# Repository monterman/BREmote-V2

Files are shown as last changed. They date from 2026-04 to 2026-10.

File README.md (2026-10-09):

# BREmote V2.5-Evo — Tow Buggy / eFoil Remote

> **Fork of [BREmote V2](https://github.com/Luddi96/BREmote) by LudwigBre / Luddi96**





ESP32 LoRa wireless remote for efoil and RC tow buggy — 868/915 MHz, 10 Hz control cycle, VESC UART telemetry, GPS speed display, integrated data logger.

**Status: Alpha — BLE + VESC Tool field-confirmed ✅ (2026-05-16). RTM encoded + working, FM coded.**

> **🌙 nightly firmware.** The sections marked *upcoming release*, the setup wizard and the new
> screens match the **nightly** firmware on the [`fm-stations` branch](https://github.com/monterman/BREmote-V2/tree/fm-stations), not the
> firmware on master. Nightly = bleeding edge, under water testing, use at your own risk.
> Binaries are in the `latest-FM-stations` folders. See [Nightly builds](#-nightly-builds).

> **⚠️ 2026-07-25 — important fix, please reflash both boards.** A bug was found in on-water testing: the shared serial line was prioritising the VESC over the GPS, so the receiver was catching only ~2% of the GPS feed and Follow-Me could steer on a dead heading. Priority is now swapped and the GPS course works. **Fixed but not yet proven on the water** — see [CHANGELOG.md](CHANGELOG.md). Read the Alpha Testing Notes below before any in-water use.**

> **🆕 Upcoming release — new Follow-Me screens, auto-return, front stations, buggy WiFi console.**
> In the nightly builds on the [`fm-stations` branch](https://github.com/monterman/BREmote-V2/tree/fm-stations) now; it moves to master
> gradually after more water testing. See [what's coming](#-coming-in-the-upcoming-release) and the
> [release notes](docs/RELEASE_NOTES_upcoming.md).

---

## 🚀 New here? Start with the setup guide

### **[→ Zero → Foiling — the complete setup walkthrough](docs/ZERO_TO_FOILING.md)**

**Out of the box to on the water, in one linear path.** Flashing, TX calibration, pairing, compass
calibration, VESC/PPM wiring and setup, the wheels-up safety check, web-portal configuration, the dry
arming test, and your first Follow-Me session. If you are setting up a BREmote for the first time,
**read that guide, not this page.**

### **[→ Setup wizard — get your settings in about 8 minutes](https://monterman.github.io/BREmote-V2/setup-wizard.html)**

Answer a few questions about your buggy, remote and riding, and the wizard gives you the settings for
both boards, ready to load with the web serial config tool (USB) or from your phone on the board's
WiFi page. *Matches the nightly firmware on the `fm-stations` branch.*

This README is the reference: what the hardware is, what changed in each version, what every setting
and status code means, and what is still broken. Come back to it once you are running.

📁 **[Browse all the detailed guides in `docs/` →](docs/)** — wiring, flashing, GPS, compass, VESC
tuning, display reference and more. The [index below](#-detailed-guides--where-to-go-deeper) says
which one you want.

---

## 📚 Detailed guides — where to go deeper

Every section of this README has a longer document behind it. Start here when you need the detail:

| If you want to… | Read |
|---|---|
| **Set up from scratch, in order** | **[Zero → Foiling](docs/ZERO_TO_FOILING.md)** ⭐ start here |
| **Flash the boards** | **[Flashing with the Flash Download Tool](docs/FLASHING_WITH_DOWNLOAD_TOOL.md)** ⭐ the normal way — no Arduino · 🎥 [video from 40:00](https://youtu.be/r6JIZEq3aTU?t=2400) |
| Compile it yourself *(advanced)* | [RX via Arduino](docs/FLASHING_RX_ARDUINO.md) · [TX via Arduino](docs/FLASHING_TX_ARDUINO.md) |
| Wire the GPS + compass to the RX | [BN-880 → RX wiring](docs/GPS_Wiring_BN880_RX.md) |
| **Mount the GPS/compass OUTSIDE the box** | **[External GPS + compass mount](docs/External_GPS_Compass_Mount.md)** ⭐ the single biggest fix for compass error — 10 in max, waterproofed, nothing ferrous |
| Understand or fix GPS | [GPS configuration](docs/GPS.md) · [GPS troubleshooting](docs/hardware/gps-troubleshooting.md) |
| Calibrate the compass | **[Zero → Foiling § 2.4](docs/ZERO_TO_FOILING.md#24-compass-calibration-rx--nose-on-north-two-clockwise-circles)** — the procedure: nose on north, two clockwise circles, finish on north |
| Chase compass EMI / understand the field data | [Compass calibration & EMI field analysis](docs/Compass_Cal_Analysis.md) *(reference, not a how-to)* |
| Read the TX screen | [Display reference](docs/display-reference.md) |
| Ride with Follow-Me | [Follow-Me guide](docs/FOLLOW_ME_GUIDE.md) · [design notes](DESIGN_FOLLOW_ME.md) |
| See the new Follow-Me screens *(upcoming release)* | **[Screens page + glance quiz](https://monterman.github.io/BREmote-V2/followme-screens.html)** |
| Get a starting config for your setup *(upcoming release)* | **[Setup wizard](https://monterman.github.io/BREmote-V2/setup-wizard.html)** |
| What the next firmware changes | [Upcoming release notes](docs/RELEASE_NOTES_upcoming.md) |
| Use Return-to-Me | [RTM design notes](DESIGN_RETURN_TO_ME.md) |
| Set up or tune the VESCs | [Smooth-start quick reference](docs/VESC_SMOOTH_START_QUICK_REFERENCE.md) · [tuning process](docs/VESC_TUNING_PROCESS.md) · [FOC notes](docs/VESC_FOC_TUNING_NOTES.md) |
| Fix VESC telemetry | [VESC telemetry fix](docs/VESC_Telemetry_Fix.md) · [telemetry sources & prop baseline](docs/TELEMETRY_SOURCE_AND_PROP_BASELINE.md) |
| Use Bluetooth / BLE | [BLE implementation](docs/BLE_Implementation.md) · [app brief](docs/BLE_App_Brief.md) |
| Pull and read logs | [Logger notes](docs/LOGGER_NOTES.md) |
| Fit the magnet / Hall sensor | [Install tutorial](docs/Hall_Sensor_Install_Tutorial.md) · [expansion notes](docs/Hall_Sensor_Expansion.md) |
| Tune heading control | [Heading control tuning](docs/Heading_Control_Tuning.md) |
| Understand the throttle path | [Throttle pipeline analysis](docs/THROTTLE_PIPELINE_ANALYSIS.md) |
| Help test, and report properly | [Beta testing sheet](docs/Beta_Testing_Sheet.md) |
| Understand the safety model | [Buggy foil domain](BUGGY_FOIL_DOMAIN.md) |

---

## Contributors

People who have tested, reported, or contributed code to **this fork** specifically. Upstream credit
for the original hardware and firmware is in [Credits](#credits) below.

| | |
|---|---|
| **[robertzach](https://github.com/robertzach)** *(heiguga)* | First outside contributor. Brought **HGLRC M100-5883** support — his [PR #1](https://github.com/monterman/BREmote-V2/pull/1) identified that the module carries a **QMC5883P at 0x2C**, not the QMC5883L the firmware assumed, and his working implementation read from register `0x01`. That independently confirmed the QST datasheet against ArduPilot's driver, which has that init write transposed — so his code was the tiebreaker on a real ambiguity. Also field-tested the dual-compass build within hours of release, and hit the Sea-model altitude ceiling at 550 m, which is why `gps_dyn_model` exists. |

---

## Credits

BREmote is a collaborative open-source project built by the efoil and esk8 community:

| Contributor | Contribution |
|---|---|
| **[LudwigBre / Luddi96](https://github.com/Luddi96/BREmote)** | **Original hardware design, original firmware architecture, project founder, and dev-logger framework (dev-logger branch). All core features originate here.** |
| **Janrusher** | Dynamic throttle cap mode and Web Console foundation — significant V2 enhancements forked from LudwigBre, further refined in V2.5-Evo |
| **monterman** | V2.5-Evo firmware: TX GPS implementation, dev-logger AUX button toggle with LED status feedback (5× flash = start, 2× flash = stop), date format DDMMYY → MMDDYY, web console major rebuild (upload/download/compare JSON, integrated serial console, TX+RX coverage, plain-English parameter docs for every setting), deep codebase analysis, critical bug documentation, RTM/FM mode design, VESC UART telemetry diagnosis and root-cause fix (SW55), DISPLAY_MODE_INTBAT 7th display mode, BT status dot + Hall sensor activation framework, BLE NUS + VESC Tool binary protocol live gauges (field-confirmed 2026-05-16) |

This fork exists because LudwigBre published open hardware and firmware under GPL 3.0. V2.5-Evo enhancements are released under the same license and dedicated back to the community.

### Branches — read this before you clone

| Branch | What it is |
|---|---|
| **`master`** | **V2.5-Evo. The default branch, and what you want.** Hardware-verified on both boards. |
| `ludwig-upstream-main` | **LudwigBre's original line, not mine.** Kept so upstream changes can be tracked and merged. Do not flash it expecting V2.5-Evo behaviour — it is a different firmware. |
| `fm-stations` | **Nightly builds** — bleeding edge, under water testing, use at your own risk: new Follow-Me screens, auto-return, front stations, buggy WiFi console. Binaries in the `latest-FM-stations` folders. Commits move to master gradually after more water testing. See [Nightly builds](#-nightly-builds). |
| `multi-tx` | Work in progress: multiple remotes sharing one buggy. **Nothing here has been flashed to hardware.** |

`ludwig-upstream-main` was called `main` until 2026-08-05. It was renamed because "main" reads
like the primary branch of *this* repo, which it is not — it is a mirror of
[Luddi96/BREmote](https://github.com/Luddi96/BREmote), whose own default branch is `main`. The
old name caused exactly the confusion the new one avoids.

---

## What Is This?

BREmote is a custom wireless remote system for efoils and RC tow buggies. The TX (handheld) sends throttle and steering over LoRa at 10 Hz. The RX (mounted on the vehicle) drives the ESC/VESC and returns telemetry.

```
┌────────────────────────────┐              ┌──────────────────────────────────┐
│      TX — Handheld         │              │       RX — Board Unit            │
│                            │              │                                  │
│  ESP32-C3                  │              │  ESP32-C3                        │
│  SX1262 LoRa               │◄──────────►  │  SX1262 LoRa                     │
│  BN-220 GPS (GPIO 18/19)   │  868/915MHz  │  BN-880 GPS  (Serial1 + I2C mux) │
│  Dot matrix display        │    10 Hz     │  Compass QMC5883L or 5883P (I2C) │
│  Hall-effect throttle      │  6-byte pkt  │  AW9523 I/O Expander (I2C)       │
│  Hall-effect toggle        │              │  VESC UART  or  ESC PWM output   │
│  Vibration motor           │              │  Servo steering output           │
│  WiFi AP — web config      │              │  WiFi AP — web config + log DL   │
│                            │              │  Flash Data Logger               │
└────────────────────────────┘              └──────────────────────────────────┘
```

---

## 🆕 Coming in the upcoming release

*In the nightly builds on the [`fm-stations` branch](https://github.com/monterman/BREmote-V2/tree/fm-stations) now (see
[Nightly builds](#-nightly-builds)). It moves to master gradually after more water testing. Flash the
remote and the buggy together.* Details: [release notes](docs/RELEASE_NOTES_upcoming.md).

- **New Follow-Me screens.** One dot hopping = waiting, two steady dots = following, the dot column
  filling down = the buggy is coming to you. The numbers are the metres between remote and buggy.
  [See them animated, with a glance quiz](https://monterman.github.io/BREmote-V2/followme-screens.html).
- **Auto-return inside Follow-Me.** Stop and the buggy parks and waits. Squeeze when you want it
  back. Pauses never cancel it; it ends by arriving, a fault, or switching the remote off and on.
- **Magnet tap** (`mag_mode` 4): a tap arms Follow-Me, even on the rope, and steps the station;
  a 2.5 s hold with the trigger released starts the manual return-to-me.
- **Front stations F4 / F5\*** — ahead-left or ahead-right for downwind runs, never dead ahead,
  with a protection cone around your path. *\* In development and testing, not yet water-tested.*
- **Serial console on the buggy's WiFi page** (RX only). Run commands from your phone at the dock
  or the beach, no laptop or cable: a dropdown of the commands the buggy allows over WiFi, a
  free-text box, and one-tap buttons for everyday jobs (Save, `?get`, North check, compass align,
  `?diag`, `?conf`, `?printgps`, `?logstat`). Save checks there is enough free space first.
- **Throttle-input fault protection.** If the remote's trigger sensor stops answering (water, a
  stuck sensor bus), the throttle goes to **zero** and the screen blinks **St**, instead of
  holding the last value.
- **Safety rules the remote now follows:** manual always wins, "St" is the one not-working
  signal, the screen shows only what the buggy confirms, auto-return waits for you, arrival keeps
  the throttle capped until one full release. See the [Follow-Me guide](docs/FOLLOW_ME_GUIDE.md#2-safety-philosophy).
- **Fewer buzzes.** No buzz for distance, station steps or the start of following. The
  distance-warning buzz is gone: `fm_warn_distance_m` now only sets the bar's full scale.
- **New defaults:** the Follow-Me numbers show metres to the buggy (`fm_display_mode` 2);
  auto-return on (`fm_return_mode` 1).
- **Setup wizard** for early adopters: answer the questions (about 8 minutes) and get a config for
  the remote and the buggy. [Open the wizard](https://monterman.github.io/BREmote-V2/setup-wizard.html).
- **Log format 3:** log level 4 now carries the second VESC too. **Download your logs before you
  flash** — after the flash the buggy can no longer open log files from older firmware.

---

## 🌙 Nightly builds

A **nightly** is a build of the newest firmware, published before it reaches master.

- **What:** bleeding edge. It is being water-tested right now. **Use at your own risk.**
- **Where:** the [`fm-stations` branch](https://github.com/monterman/BREmote-V2/tree/fm-stations). Binaries:
  `Source/V2_Integration_Rx/RX firmware/latest-FM-stations/` (buggy) and
  `Source/V2_Integration_Tx/TX firmware/latest-FM-stations/` (remote). They are kept apart from
  the older binaries in those folders. Flash the remote and the buggy together, and download your
  logs and back up your settings first.
- **How often:** new nightlies keep coming as fixes land.
- **Master stays the stable line.** Nightly commits move to master gradually, after more water testing.
  If you want the tested firmware, stay on master.

Found a problem on a nightly? Please report it with your firmware version (`?conf` shows it) and,
if you can, the log of that session.

---

## What's New in V2.5-Evo

| Feature | V2 | V2.5-Evo |
|---|---|---|
| TX GPS speed display (mph / km/h / knots) | ❌ | ✅ |
| GPS speed source SPIFFS-configurable | ❌ | ✅ |
| Data logger AUX button toggle + LED feedback *(logger by LudwigBre)* | ❌ | ✅ |
| Log download over WiFi web UI | ❌ | ✅ |
| US-format log filenames (MMDDYY) | ❌ | ✅ |
| Web Serial Config Tool (offline HTML, USB serial) | ❌ | ✅ |
| Full codebase audit + stability fixes (7 critical) | ❌ | ✅ |
| GPS anti-spoofing: Phase A (RX standalone) | ❌ | ✅ |
| GPS anti-spoofing: Phase B (TX↔RX handshake) | ❌ | ✅ |
| GPS anti-spoofing: Phase C (RTM convergence) | ❌ | ✅ |
| TX→RX GPS coordinate meta-packets (0xF3) | ❌ | ✅ |
| Return-to-Me mode (RTM) | ❌ | ✅ |
| Follow-Me mode override (FM) | ❌ | ✅ |
| RTM/FM info display (distance/speed on TX) | ❌ | ✅ |
| BLE live telemetry — VESC Tool / VESC App (iOS/Android, free) | ❌ | ✅ |
| NUS + VESC binary protocol (COMM_GET_VALUES, auto-detected) | ❌ | ✅ |
| Gauges: FET temp, motor amps, duty, voltage, RPM | ❌ | ✅ |

---

## Hardware Requirements

> 📖 Wiring the GPS + compass: [BN-880 → RX guide](docs/GPS_Wiring_BN880_RX.md). Fitting the magnet: [Hall sensor tutorial](docs/Hall_Sensor_Install_Tutorial.md).

| Component | TX (Handheld) | RX (Board Unit) |
|---|---|---|
| MCU | ESP32-C3 | ESP32-C3 |
| Module | HT-CT62 (ESP32-C3 + SX1262 + WiFi + **BLE** integrated) | HT-CT62 |
| Radio | SX1262 LoRa | SX1262 LoRa |
| BLE | Built-in (ESP32-C3) — NUS + VESC Tool protocol ✅ in master; `bt_enabled` SPIFFS config (0=off, 1=Hall-mode, 2=always-on) | Built-in (ESP32-C3) — RX BLE planned |
| GPS | BN-220 or [HGLRC M100 Mini](https://www.hglrc.com/products/hglrc-m100_mini-gps) (M10 chip, no compass, 3.3V–5V) | BN-880 or [HGLRC M100-5883](https://www.hglrc.com/products/m100-5883-gps) (M10 chip + compass) |
| Compass | None | QMC5883L (I2C `0x0D`) **or** QMC5883P (I2C `0x2C`) — auto-detected at boot |
| Display | HT16K33 dot matrix (I2C 0x70) | None |
| ADC | ADS1115 (I2C 0x48) | None |
| I/O Expander | None | AW9523 (I2C) |
| ESC / VESC | None | VESC UART or PWM (RMT GPIO 9) |

> ⚠️ **TX GPS must be 3.3V tolerant** — the ESP32-C3 supplies 3.3V only. Both the BN-220 and HGLRC M100 Mini meet this requirement.

> 🔌 **Wiring the RX GPS + compass:** **[BN-880 → RX wiring guide →](docs/GPS_Wiring_BN880_RX.md)** — six wires,
> pin map, and the three things that bite: every wire runs **straight, label to label** (the PCB does the UART
> crossover for you), the BN-880 needs **5 V**, and `gps_chip_type` must be set to your module.

---

## Quick Start

> 🚀 **Setting up for the first time? Follow [Zero → Foiling](docs/ZERO_TO_FOILING.md) instead** — it covers the same ground in order, with the VESC/PPM and safety steps this summary skips.

> ⚠️ **`master` ships SAFE factory defaults — unbound and uncalibrated** (no pairing, neutral compass/throttle calibration). After flashing you **must** set up your own devices: pair TX↔RX, run TX calibration (hold LEFT toggle at boot), and run `?compasscal` on RX. Until you do, the remote won't respond correctly to your throttle or compass.

1. **Flash firmware** — easiest is a prebuilt `.bin`, no toolchain needed (see below).

   **🟢 Simple — flash a prebuilt `.bin` (recommended, no compiling)**

   Ready-to-flash binaries live next to their source, with a README in each folder explaining
   which build is which:

   | Board | Folder |
   |---|---|
   | TX | **[`Source/V2_Integration_Tx/TX firmware/`](Source/V2_Integration_Tx/TX%20firmware/)** |
   | RX | **[`Source/V2_Integration_Rx/RX firmware/`](Source/V2_Integration_Rx/RX%20firmware/)** |

   > 🚨 **Download the RAW file — this is where people go wrong.** Click the `.bin` on GitHub, then
   > use the **Download raw file** button (⤓, top-right of the file view). Do **not** use your
   > browser's *Save Page As* — that saves an HTML page with a `.bin` name, which will not flash and
   > looks like a dead board. Or clone the repo and take it from the folder:
   > `git clone https://github.com/monterman/BREmote-V2.git`
   >
   > **Sanity check:** a real image is a few hundred KB. A few KB, or something that opens as a web
   > page in a text editor, means you saved the HTML.

   Download the `.bin` you want, then use **either**:

   - ⭐ **[Flash Download Tool](https://www.espressif.com/en/support/download/other-tools)**
     (Espressif's Windows GUI — also called the ESP Download Tool) — **the recommended way.**
     🎥 **[Ludwig demonstrates it from 40:00](https://youtu.be/r6JIZEq3aTU?t=2400)**.
     Chip `ESP32-C3`, load the `.bin` at address **`0x10000`**, press START.
     **[Full step-by-step guide →](docs/FLASHING_WITH_DOWNLOAD_TOOL.md)**
   - **esptool** (any OS, one line):
     ```bash
     esptool --chip esp32c3 --port COM<N> write-flash 0x10000 <the-file>.bin
     ```

   > **`0x10000` is the address that matters.** These are app-only images, so the *flash itself*
   > never touches the partition table or SPIFFS.
   >
   > ⚠️ **That does not mean your settings always survive.** On boot the firmware compares the
   > stored config version against its own and **rewrites config to defaults when they differ**
   > (`Common/SPIFFSEngine.h`). So flashing a build with a **different `SW_VERSION`** wipes your
   > pairing, calibration and settings even though the flash left SPIFFS alone — and rolling back,
   > then coming forward again, wipes it twice. Same version in, same version out = settings kept.
   > **[Back up first →](#-backing-up-your-settings--read-this-before-you-flash)**
   >
   > Identify the board by MAC (`esptool --chip esp32c3 --port COM<N> read-mac`) rather than by
   > COM number: TX and RX are the same chip and COM numbers move between reboots.

   ⚙️ **Compiling it yourself? (advanced)** Follow the per-board guides — the partition settings
   **differ between TX and RX**, and the wrong one wipes config:
   **[RX flashing guide →](docs/FLASHING_RX_ARDUINO.md)** · **[TX flashing guide →](docs/FLASHING_TX_ARDUINO.md)**
2. **Power on both TX and RX** — TX shows `EP` (not paired) on first boot
3. **Pair** — hold RIGHT toggle on TX at boot; hold BIND on RX at boot simultaneously
4. **Connect to WiFi AP** — SSID shown on the device; default password `12345678` *(power off the other device first — see WiFi note below)*
5. **Open the Web Serial Config Tool** — configure all parameters with plain English labels
6. **Calibrate TX** — hold LEFT toggle at boot, follow the display prompts
7. **Calibrate RX compass** — **first check the module is mounted square to the buggy** (lined up with the nose, or turned exactly 90° / 180° / 270° from it — **not diagonal**; the firmware stores only those four values, so a module at 30° is stored as 0° and keeps 30° of error no calibration can remove). Then **point the nose of the buggy at NORTH** and run `?compasscal` (RX serial at 115200 baud, or short-press BIND) and **turn it slowly CLOCKWISE through two full circles, finishing back on north.** One run sets the iron calibration, the mounting handedness and the mounting orientation. **BIND LED: 2 blinks = full success. 3 blinks = PARTIAL** — the iron calibration saved but the mounting orientation did not, so walk it again. Full procedure: **[Zero → Foiling § 2.4](docs/ZERO_TO_FOILING.md#24-compass-calibration-rx--nose-on-north-two-clockwise-circles)**

---

## 🛠️ Web Configuration Interfaces

BREmote V2.5-Evo has three separate web configuration interfaces:

> ⚠️ **WiFi turns off automatically when TX and RX are paired and in range.** LoRa takes precedence over WiFi. To access the web UI on either device, make sure the **other device is powered off** — otherwise the LoRa link forms, WiFi shuts down, and you cannot connect. Once you have finished configuring, power the other device back on.

### 1. TX Embedded Web Page
Served by the TX WiFi AP for the first 120 seconds after boot. Connect to the TX WiFi AP and open the device IP in any browser. Configures all TX SPIFFS parameters with valid range hints.

### 2. RX Embedded Web Page
Served by the RX WiFi AP for the first 120 seconds after boot. Configures all RX SPIFFS parameters and provides log file management (list, download, delete).

### 3. BREmote V2.5-Evo — Web Serial Config Tool *(standalone, offline)*

The most capable interface. Connects to TX or RX via USB serial (requires Chrome or Edge).

**Open directly — no download needed:**
[https://monterman.github.io/BREmote-V2/BREmote_V2.5-Evo_Web_Serial_Config_Tool.html](https://monterman.github.io/BREmote-V2/BREmote_V2.5-Evo_Web_Serial_Config_Tool.html)

**Or download for fully offline use:** [`docs/BREmote_V2.5-Evo_Web_Serial_Config_Tool.html`](docs/BREmote_V2.5-Evo_Web_Serial_Config_Tool.html)

**What it does:**
- Configure both TX and RX — switch between boards without leaving the page
- Upload / download / compare two configurations side by side
- Integrated serial console with custom commands dropdown
- Extensive plain-English descriptions for every parameter — you know what each setting does and its valid range before you change it
- Export config as **JSON** or **Base64** (for serial paste)
- Log file download and management
- Dirty-state highlighting — changed fields highlighted until saved
- Works fully offline after download

### 💾 Backing up your settings — read this before you flash

Flashing a build with a different config version **resets every setting to defaults**. Back up first,
and know which format to use:

| Format | Use it for | Survives a firmware update? |
|---|---|---|
| **Base64** ✅ | **Backup / restore across firmware versions** | **Yes** — raw copy of the config block, restores as-is |
| **JSON** | Reading, editing, diffing, sharing settings with someone | **Not always** — see below |

> ⚠️ **Use Base64 for backups.** JSON is keyed by field *name*, so if a setting was renamed or
> replaced between versions, the import is **rejected as an unknown field** and you lose the restore.
> Base64 is a straight copy of the config block and does not care what the fields are called.
>
> JSON is still the better format when you want to *read* your settings, compare two boards, or send
> a config to someone for troubleshooting — just don't rely on it as your only backup.

**Recommended before any flash:**
1. Connect the board in the Web Serial Config Tool
2. Export **Base64** — keep it (this is the restore file)
3. Export **JSON** as well — human-readable reference if you ever need to rebuild by hand
4. Flash, then paste the Base64 back and **`?save`**
5. **Re-run calibration anyway** — `?compasscal` on RX, LEFT-toggle calibration on TX. Stored
   calibration is only as good as the mounting it was taken in.

---

## TX Features

### Standard Features (V2)

- Hall-effect throttle with calibration
- Hall-effect toggle for steering and gear/menu input
- Dot matrix display showing telemetry modes
- LoRa packet transmission at 10 Hz
- Gears mode, no-gears mode, dynamic throttle cap mode
- Configurable throttle expo curve
- System lock / unlock sequence
- Vibration motor feedback
- Internal battery voltage monitoring
- USB charging detection and display
- Pairing with address-based authentication
- WiFi AP for web configuration
- Serial USB configuration interface (`?conf`, `?conf json`, `?printtasks`, etc.) — also configurable via the [BREmote V2.5-Evo Web Serial Config Tool](https://monterman.github.io/BREmote-V2/BREmote_V2.5-Evo_Web_Serial_Config_Tool.html), which is easier than raw serial and includes plain-English descriptions for every parameter

### V2.5-Evo: TX GPS Speed Display

The **SP** (Speed) telemetry display mode can now read speed directly from the TX GPS module (BN-220 on Serial1), eliminating dependence on the LoRa telemetry round-trip. Configure `speed_src` in Config Studio or the web UI:

| `speed_src` | Source | Unit | Status |
|---|---|---|---|
| 0 | RX GPS | km/h | V2 original |
| 1 | RX GPS | knots | V2 original |
| 2 | TX GPS | km/h | ✅ V2.5-Evo |
| 3 | TX GPS | knots | ✅ V2.5-Evo |
| 4 | RX GPS | mph | ✅ V2.5-Evo |
| 5 | TX GPS | mph | ✅ V2.5-Evo |

Display shows `--` when no fix is available or the fix is older than the configured stale timeout. Set `gps_en = 1` and reboot after changing it.

#### GPS — V2.5-Evo (2026-07-31)

Every GPS config write is now acknowledgement-verified, and the firmware auto-detects whether
your module speaks the u-blox 6/7/8 or the M9/M10 dialect — so a BN-220, BN-880 or M10 all
self-configure from one image. 📖 **[`docs/GPS.md`](docs/GPS.md)** explains the design, why
`dynModel=Sea` matters (and the ⚠️ 500 m altitude caveat), and how to recover a GPS that has
stopped accepting commands.

Two things worth knowing up front:

- **Riding above ~500 m?** The Sea navigation model has a 500 m ceiling. On the RX that is a
  setting, not a recompile: `?set gps_dyn_model 4` then `?save` switches it to Automotive.
- **A GPS that shows nothing at all** is often a module that came off a flight controller —
  Betaflight leaves u-blox modules **UBX-only with NMEA output disabled**, saved in the module's
  own memory. The RX now recognises that during its listen-only baud scan and switches NMEA back
  on: flash the current RX firmware and run **`?gpssetup`**. This used to need u-center on a PC.

<details>
<summary>Older detail — wiring, commands and recovery steps</summary>

📖 **Wiring & troubleshooting: [`docs/hardware/gps-troubleshooting.md`](docs/hardware/gps-troubleshooting.md)**

**Fitting a new GPS?** Plug it in, power on, then run `?gpscfg` and check it reads
`dynModel : 5 (Sea)`. The firmware finds the module at whatever baud it ships on and
configures it — BN-220, BN-880, NEO-M8N, NEO-M9N and MAX-M10S all work from the same image,
with no chip-specific setting to declare.

Optionally run **`?gpssetup` once** per remote. It raises the module to 115200, applies every
setting with the acknowledgement checked, and writes the result to the **module's own flash**
so it survives a power cycle.

**Every UBX configuration write is now acknowledgement-verified.** Previously the firmware
sent configuration blind and could not tell a successful write from an ignored one — which is
how a receiver ended up running `dynModel 0 (Portable)` while the logs said `Sea`. Portable
permits 310 m/s horizontal and 50 m/s vertical solutions, and has been observed producing
254 km/h and 4800 m readings as *high-confidence* fixes. Boot now prints the outcome of each
write, and `?gpscfg` reads the setting back **out of the module** as an independent check.

🚨 **If the GPS reports position but rejects all configuration** — boot showing `no-ACK` on
every line, or `?gpsbaud` showing NMEA present but *"UBX input: DEAD"* — the module has
disabled its own UART receiver after accumulated framing errors.

> **Fix: unplug USB, then flip the power switch off. Wait 2 s, power back on.**
> Unplugging USB cuts power fully on both TX and RX; on the TX the switch also guarantees the
> internal cell is not still running the module. A reboot, a reset or a re-flash will **not**
> clear it — the GPS has to actually lose power, which is also why no serial command can fix
> it (the module has stopped listening). No re-flashing is required.

| Command | Purpose |
|---|---|
| `?gpscfg` | Read `dynModel` back out of the module — proves what it is actually running |
| `?gpsbaud` | Listen-only baud scan; reports whether UBX input is alive |
| `?gpssetup` | One-time full setup, saved permanently into the module |
| `?gpsraw` | Raw NMEA dump when nothing else responds |

All are USB-only bench commands (the TX disables serial on a battery boot) and none affect the
LoRa link.

</details>

**Telemetry display cycle** (cycle with RIGHT toggle hold 2 s):

```
TP    → TH       → SP    → PV    → MA           → UB           → BA
Temp  → Throttle → Speed → Power → Motor Amps   → Internal Bat → Foil Bat
```

Unavailable modes (no VESC lock or no GPS fix) are skipped automatically. `MA` requires VESC telemetry; `SP` with RX GPS source requires GPS fix (TX GPS source always shows, using `--` when no fix).

**PV** shows VESC battery-side power in kW with one decimal (e.g., `4.4` = 4400 W). Capped at 9.9 kW.

### TX Toggle Button Reference — V2.5-Evo P8 Gestures

| Input | Result |
| --- | --- |
| Boot + hold LEFT toggle | Calibration mode |
| Boot + hold RIGHT toggle | Pairing mode |
| Boot + THR + LEFT toggle | Force BLE for session — activates BLE regardless of `bt_enabled` setting; display shows `bt`; persists until reboot |
| Boot + THR + RIGHT toggle | Delete SPIFFS config (factory reset) |
| LEFT hold 2 s | Lock the Remote |
| RIGHT hold 2 s | Cycle telemetry display mode |
| RIGHT tap → LEFT hold (default 5 s, tunable 3–10 s) | Arm **Return-to-Me** (RTM) — display shows `rn` |
| LEFT tap → RIGHT hold (default 5 s, tunable 3–10 s) | Cycle **Follow-Me** override mode (F0/F1/F2/F3) |

> 💡 **Optional — magnet / Hall input for hands-free control.** A DRV5032 Hall sensor on GPIO 9 (P_MAG) lets a magnet gesture arm **Follow-Me** and start **Return-to-Me** without reaching for the toggles (great mid-ride). With `mag_mode` 0 it keeps its older job of switching **BLE** on. *Upcoming release:* `mag_mode` 4 — tap to arm Follow-Me or step the station, hold 2.5 s (trigger released) for return-to-me. ⚠️ Never power the remote on with the magnet against it: GPIO 9 is a boot pin. Wiring + firmware: **[Hall Sensor Expansion guide →](docs/Hall_Sensor_Expansion.md)** · step-by-step fitting (incl. easier-to-solder parts): **[install tutorial →](docs/Hall_Sensor_Install_Tutorial.md)**.

> 

---

## RX Features

### Standard Features (V2)

- VESC UART telemetry (battery %, FET temperature, speed, power)
- Single motor, differential motor, or servo steering output
- PWM output via RMT (GPIO 9) and AW9523 I/O expander
- Water ingress detection with safety stop
- Configurable failsafe time (motor stop on LoRa link loss)
- Foil battery cell count and voltage monitoring
- BMS input: two pads on the RX board, **BMS+** and **BMS−** (see the silkscreen). The current firmware does not use it yet.
- GPS positioning (BN-880 or HGLRC M100-5883)
- Compass (I2C, fully calibrated) — **either a QMC5883L at `0x0D` (BN-880) or a QMC5883P at `0x2C` (HGLRC M100-5883), detected automatically at boot and driven by the matching driver**; one firmware image, nothing to set. RTM uses GPS COG as primary heading, compass snapshot as low-speed fallback; pure compass mode available as diagnostic option (`rtm_use_compass=2`)
- Kalman filter on GPS data
- Follow-me mode framework (positional modes: behind, near right, near left)
- WiFi AP for web configuration and log management

### V2.5-Evo: Data Logger *(framework by LudwigBre — AUX toggle by monterman)*

> **Leave `logger_en` at 0 — that is the recommended setting.** The RX then boots with logging off and
> never fills SPIFFS while parked or on the bench. **Short-press AUX whenever the RX is running to
> start logging (AUX LED blinks 5×), and short-press again to stop (2 blinks)** — logging per session,
> on demand. `logger_en=1` only means it starts recording the instant it powers up, moving or not.
> Seeing `logger_en=0` at boot is correct behaviour, not a fault.

The RX board logs GPS position, VESC telemetry, voltage, speed, and timestamps to on-board flash storage.

> **Keep `logger_en = 0` (the default).** Use the AUX button to start and stop individual logging sessions. If you set `logger_en = 1`, the logger starts automatically on every boot and logs continuously — not recommended, as it fills flash quickly and runs without GPS-lock confirmation.

**Starting and stopping a session:**

| Action | LED | Meaning |
|---|---|---|
| Press AUX once | 5× flash | Logging session started |
| Press AUX once again | 2× flash | Logging session stopped |

**Tips:**
- **Wait for GPS lock** before pressing AUX — entries without a valid fix record zero coordinates
- **WiFi auto-disables** while logging to reduce current draw and RF interference with GPS
- **Brownout warning:** the logger auto-stops if supply voltage drops below threshold; WiFi + logging together draw significant current — ensure adequate power supply
- **File format:** `MMDDYY_HHMMSS.csv` (UTC, US date order) *
- **Download:** Connect to RX WiFi AP → open the RX embedded web page or the Web Serial Config Tool → **Manage Logs** section
- **Log rate:** default **3 Hz**, tuned for propeller / max-speed testing. Raise to 5 Hz for RTM/steering analysis with `?lograte 5` over serial (resets to 3 Hz on reboot; not persisted). Record size, rate→duration table, and SPIFFS capacity: see `docs/LOGGER_NOTES.md`.

*\* Date format changed from DDMMYY (original LudwigBre) to MMDDYY in V2.5-Evo.*

> **Upcoming release — log format 3.** Level 4 logs gain the second VESC. **Download every log
> before you flash the new buggy firmware:** afterwards the buggy refuses to open files written by
> older firmware (the PC log reader on the `fm-stations` branch still reads them).

---

## 🛡️ Safety Philosophy

> 📖 The full model, and why it is built this way: [BUGGY_FOIL_DOMAIN.md](BUGGY_FOIL_DOMAIN.md)

> **The Tow Buggy ONLY moves when the user physically holds the throttle trigger.**

This rule is non-negotiable and is enforced at the firmware level — it cannot be configured away:

- Autonomous assist modes can **only subtract from throttle** — they can never add to it
- Releasing the throttle trigger stops the buggy **immediately**, regardless of any active mode
- No loiter, no station-keeping, no position hold, no autonomous parking
- Return-to-Me and Follow-Me can adjust steering and reduce throttle — they cannot independently spin the motor
- Without active user throttle input, the buggy motor **never moves** under any circumstance

**Added in the upcoming release** (full text in the [Follow-Me guide](docs/FOLLOW_ME_GUIDE.md#2-safety-philosophy)):

- **Manual always wins** — when GPS, compass or any automatic mode fails, the automation turns itself off and you drive home by hand.
- **"St" is the one signal** for anything that stopped or was refused.
- **The screen shows only what the buggy confirms** — no "wannabe" states, no frozen numbers.
- **Auto-return waits for the rider** — "waiting" means a squeeze will bring it; if it can't, you get St.
- **Arrival keeps a throttle cap until one full release**, so a buggy arriving at full throttle can't hit you.

---

## Return-to-Me (RTM) — Full Guide

> 📖 Design and rationale: [DESIGN_RETURN_TO_ME.md](DESIGN_RETURN_TO_ME.md). Setup in order: [Zero → Foiling](docs/ZERO_TO_FOILING.md).

> RTM is fully implemented in V2.5-Evo. Hardware: GPS on both TX and RX, compass on RX.

> **Display note:** The TX dot matrix shows lowercase **`rn`** while Return-to-Me is active. `rn` = Return to Me = RTM. All SPIFFS parameters and code use the `rtm_` prefix — RTM is the canonical name for this mode.

For when you are in the water and want the buggy to drive itself toward you. **You must actively hold the throttle** — RTM provides automatic GPS+compass-bearing steering only; it cannot drive the motor independently. Releasing the trigger stops the buggy immediately.

### Arming

1. **Combo gesture:** Quick-tap RIGHT toggle, then within 3 seconds hold LEFT toggle for the arm-hold duration (`rtm_hold_duration_s`, default 5 s, tunable 3–10 s)
2. TX display shows `rn` for 3 s (two 1.5 s static passes) — armed
3. Haptic: 2 fast short pulses confirm arm

### Engaging

With RTM armed, press throttle to engage (10-second arm window):
- **Single-squeeze mode** (`rtm_double_squeeze_en = 0`): hold throttle >30% for 500 ms
- **Double-squeeze mode** (`rtm_double_squeeze_en = 1`, default): squeeze, release, squeeze again

### Active Operation

- Throttle ramps from `rtm_throttle_start_pct` (default 30%) to `rtm_throttle_max_pct` (default 70%) over `rtm_ramp_duration_s` seconds
- TX display shows distance to TX (in metres) or speed, per `rtm_display_mode`
- RX auto-steers toward TX GPS position — **heading source is GPS COG (primary) + compass snapshot (fallback at low speed)**. See heading modes below.
- Distance-to-TX shown in tenths of metre below 10 m (e.g. `3.5`), whole metres above

#### Heading Source — `rtm_use_compass` SPIFFS field (RX)

The compass was removed as primary steering source due to motor EMF biasing the QMC5883L by 100°+ under throttle. Steering now uses a layered heading strategy:

| `rtm_use_compass` | Mode | Behavior |
|---|---|---|
| `0` | GPS COG only | Uses GPS course-over-ground exclusively. Safest for all EMI builds. Requires minimum speed (`rtm_cog_min_speed_kmh`) to produce a valid bearing. |
| `1` *(default)* | Hybrid | GPS COG primary above min speed. Falls back to compass snapshot when buggy is too slow for GPS COG to be reliable. Snapshot is captured automatically every ~100 ms **only when motor is idle** (no throttle), so it is always an EMI-free reading. |
| `2` | Compass only | Diagnostic use only. Do not use on water with EMI-affected hardware. |

The compass snapshot is taken continuously by `updateCompassSnapshot()` whenever `thr_received < 25` — no user action required. As soon as throttle engages, GPS COG + PD control takes over.

### Disengaging

RTM stops automatically when **any** of these conditions occur:

| Safety Gate | Condition |
|---|---|
| Throttle release | User releases trigger → buggy stops (Gate 1, unconfigurable) |
| Hard stop distance | Buggy within `rtm_stop_distance_m` of TX (**default 10 m**) |
| GPS lost — TX | TX GPS older than `rtm_gps_timeout_ms` (default 2000 ms) |
| GPS lost — RX | RX GPS older than 6 s |
| GPS rejected | Phase A anti-spoofing failure on RX |
| Handshake failed | Phase B TX↔RX position cross-check failed |
| Throttle idle 10 s | No throttle input for 10 consecutive seconds while active |
| LoRa link lost | No packet for failsafe timeout |
| Max runtime | If `rtm_max_runtime_s > 0` (default: 0 = disabled) |
| Convergence fail | Distance to TX not decreasing (Phase C, checked every 5 s) |
| Steering input | Steering override while `rtm_steer_exit_on_input = 1` (default) |

On any gate failure: throttle → 0, TX display shows `St` for 2 s, haptic confirms disarm.

### SPIFFS Configuration (TX)

<details>
<summary><strong>Click to expand: RTM TX SPIFFS parameters (12 fields)</strong></summary>

<br>

| Parameter | Default | Description |
|---|---|---|
| `rtm_enabled` | 1 | Master on/off switch |
| `rtm_hold_duration_s` | 5 | LEFT-hold duration to arm RTM, in seconds (4–10) |
| `rtm_throttle_start_pct` | 30 | Initial throttle cap % when RTM engages |
| `rtm_throttle_max_pct` | 70 | Max throttle cap % after ramp |
| `rtm_ramp_duration_s` | 5 | Ramp time start→max in seconds |
| `rtm_arm_window_s` | 10 | Seconds to engage throttle after arming |
| `rtm_double_squeeze_en` | 1 | 1=double-squeeze, 0=hold 500ms |
| `rtm_disengage_distance_m` | 10 | TX-side disengage distance in metres |
| `rtm_gps_timeout_ms` | 2000 | TX GPS stale timeout in ms |
| `rtm_max_runtime_s` | 0 | Max runtime (0 = disabled) |
| `rtm_display_mode` | 0 | 0=distance, 1=speed, 2=alternating |
| `rtm_steer_exit_on_input` | 1 | 1=steering exits RTM, 0=correction blend |

</details>

### SPIFFS Configuration (RX)

<details>
<summary><strong>Click to expand: RTM RX SPIFFS parameters (8 fields)</strong></summary>

<br>

| Parameter | Default | Description |
|---|---|---|
| `rtm_rx_enabled` | 1 | RX-side RTM enable |
| `rtm_rx_override_steering` | 1 | Allow RX to auto-steer (0=disable steering override) |
| `rtm_compass_required` | 1 | Require at least one valid heading source before RTM runs; 0=bypass (advanced only) |
| `rtm_use_compass` | 1 | Heading source mode: 0=GPS COG only, 1=Hybrid GPS+snapshot (default), 2=Compass only (diagnostic) |
| `rtm_cog_min_speed_kmh` | 3 | Minimum speed (km/h) for GPS COG to be considered reliable. Below this, falls back to compass snapshot. |
| `rtm_stop_distance_m` | **10** | RX-side hard stop distance — do not go below 10; under ~10 m is inside GPS error |
| `rtm_vesc_speed_diff_kmh` | 20 | Max VESC vs GPS speed diff (Phase C) |
| `vesc_erpm_per_kmh` | 0 | VESC ERPM per km/h for speed check (0=disabled) |

</details>

---

## Follow-Me Mode Override (FM) — Full Guide

> 📖 Rider-facing guide: [FOLLOW_ME_GUIDE.md](docs/FOLLOW_ME_GUIDE.md) · design notes: [DESIGN_FOLLOW_ME.md](DESIGN_FOLLOW_ME.md)

> FM override is fully implemented in V2.5-Evo. It overrides the RX follow-me positioning mode at runtime without a SPIFFS write.

> **⚠️ Follow-Me autonomous control IS implemented in this release (alpha).** The mode override display (F0 / F1 / F2 / F3) is fully functional — you cycle and set the mode on the TX display, and the buggy follows the rider per the selected geometry. The control law is specified in [`DESIGN_FOLLOW_ME.md`](DESIGN_FOLLOW_ME.md) and coded. **Alpha — bench/wheels-up test the steering direction before any in-water use.**

The override is RAM-only — RX returns to its web-configured `followme_mode` on reboot.

### Activation

1. **Combo gesture:** Quick-tap LEFT toggle, then within 3 seconds hold RIGHT toggle for the hold duration (`fm_hold_duration_s`, default 5 s, tunable 3–10 s)
2. TX display shows `F` + mode number (e.g. `F0`, `F1`, `F2`, `F3`)
3. Continue holding RIGHT or re-hold within 2 s to keep cycling modes
4. Release and wait 2 s — TX sends the selected mode to RX via 0xF2 meta-packet

### Modes

| Display | `followme_mode` value | Behaviour |
|---|---|---|
| `F0` | 0 | Disabled — follow-me off |
| `F1` | 1 | Near-Right — RX trails behind-right of the rider |
| `F2` | 2 | Behind (default) — RX trails directly behind the rider |
| `F3` | 3 | Near-Left — RX trails behind-left of the rider |

### FM Proximity Warning

If TX-to-RX distance drops below `fm_warn_distance_m` (default 150 m), TX fires a 2×Pattern-2 vibration burst warning (2 short × 2, with 300 ms gap).

> **Upcoming release:** this buzz is removed. `fm_warn_distance_m` only sets the distance that fills the bar. The station cycle no longer lands on `F0`. New screens, auto-return and the magnet tap are in the [Follow-Me guide](docs/FOLLOW_ME_GUIDE.md).

### FM Engage Distance — measure your rope first (RX)

> **⚠️ Set this before your first Follow-Me session.**

`fm_engage_dist_m` (RX web UI: **Follow-Me → FM Engage Distance**) is how far you have to get from the buggy before Follow-Me is allowed to engage for the first time. It is the tow-rope interlock: it exists so FM can never take over while you are still on the rope.

**Measure your own tow rope, then set this to at least one metre more than the rope length.** Example: a 20 ft (6.1 m) rope → set **8 m or more**. A longer rope needs a bigger number.

- Valid entries are `0` = auto, or **8–50 m**. The firmware rejects anything between 0 and 8, and clamps an older stored value up to 8 m.
- **8 m is the enforced minimum, not a recommendation** — it is only enough for a rope of about 7 m or shorter.
- Setting it at or below your rope length would let Follow-Me engage while you are still **on** the rope, which is exactly what the interlock prevents.
- `0` = auto: the firmware works it out as 1.5 × (Min Distance + Smoothing Band). Use a measured value if you know your rope.
- You have to stay beyond this distance for 2 seconds before Follow-Me can engage.

### SPIFFS Configuration (TX)

<details>
<summary><strong>Click to expand: FM TX SPIFFS parameters (3 fields)</strong></summary>

<br>

| Parameter | Default | Description |
|---|---|---|
| `fm_override_enabled` | 1 | Master on/off switch |
| `fm_hold_duration_s` | 5 | RIGHT-hold duration to cycle FM mode, in seconds (4–10) |
| `fm_warn_distance_m` | 150 | Proximity warning threshold in metres. *Nightly: no buzz; only the distance that fills the bar.* |

</details>

---

## Status / Error Codes

### TX

| Display | Meaning |
|---|---|
| `XX` | Power saver mode active |
| `EP` | Not paired — hold RIGHT toggle at boot to pair |
| `EC` | Not calibrated — hold LEFT toggle at boot |
| `ESV` | Config version error — SPIFFS config incompatible with this firmware version |
| `ESP3` | SPIFFS error |
| `ESP4` | SPIFFS error |
| `EHFC` | LoRa channel error |
| `EHFI` | LoRa init error |
| `EHFP` | LoRa parameter error |
| `ECH` | Charger error |
| `E 7` | Water ingress detected — blinking full-screen alert + 5 long vibrations; motor output **not** cut (see below) |
| `rn` | Return-to-Me (RTM) mode active |
| `F0` | Follow-Me override: disabled |
| `F1` | Follow-Me override: Near-Right |
| `F2` | Follow-Me override: Behind (default) |
| `F3` | Follow-Me override: Near-Left |
| `St` | Stop — RTM or FM safety gate triggered, or arming blocked. *Upcoming release:* the one signal for anything stopped or refused |
| `St` blinking | *Upcoming release:* throttle input fault — the remote's trigger sensor stopped answering, throttle forced to zero |
| `99` | Full throttle reached (100%) |

### RX

| Indicator | Meaning |
|---|---|
| AUX blink 3× | SPIFFS init error |
| AUX blink 2× | Config version error |
| AUX blink 4× | SPIFFS write error |
| BIND — short periodic blink | Not paired |
| BIND — blinking | Paired, not connected |
| BIND — solid | Connected |
| BIND — blink 2× | TX power error |
| BIND — blink 3× | LoRa setting error |
| BIND — blink 4× | LoRa init error |

### Water Ingress Detection (E71)

When the RX detects moisture inside the buggy housing it sends an **E71** alert to the TX remote.

**What you will see and feel:**
- TX display flashes `E 7` full-screen (250 ms on / 250 ms off)
- TX vibrates with 5 long pulses (500 ms each) — the strongest haptic pattern
- **Motor output is NOT cut** — you can keep riding and drive the buggy back to the beach safely

**How the alert cycle works:**

| Step | What happens | When |
|---|---|---|
| 1 — Confirm | RX requires 2 consecutive wet readings ~20 s apart before alarming. A single splash or brief electrical noise is silently ignored. | — |
| 2 — Alert | `E 7` appears on TX, 5 long buzzes fire. | t = 0 |
| 3 — Auto-clear | Display clears automatically. No power cycle needed. | t ≈ +10 s |
| 4 — Snooze | Sensor stays quiet for ~5 minutes even if still wet — you are not buzzed repeatedly during the ride back. | t ≈ +10 s to +5 min |
| 5 — Repeat | If the buggy is still wet after the snooze the cycle restarts from step 1. | t ≈ +5 min |

To disable wetness detection: set `wet_det_active = 0` in the web configurator.

---

## Display Layout

> 📖 **Full screen-by-screen walkthrough: [Display reference →](docs/display-reference.md)** — every cell, every icon, every state.

The TX uses a 10×7 LED dot matrix (two 5×7 matrices side by side, driven by HT16K33 at I2C 0x70).

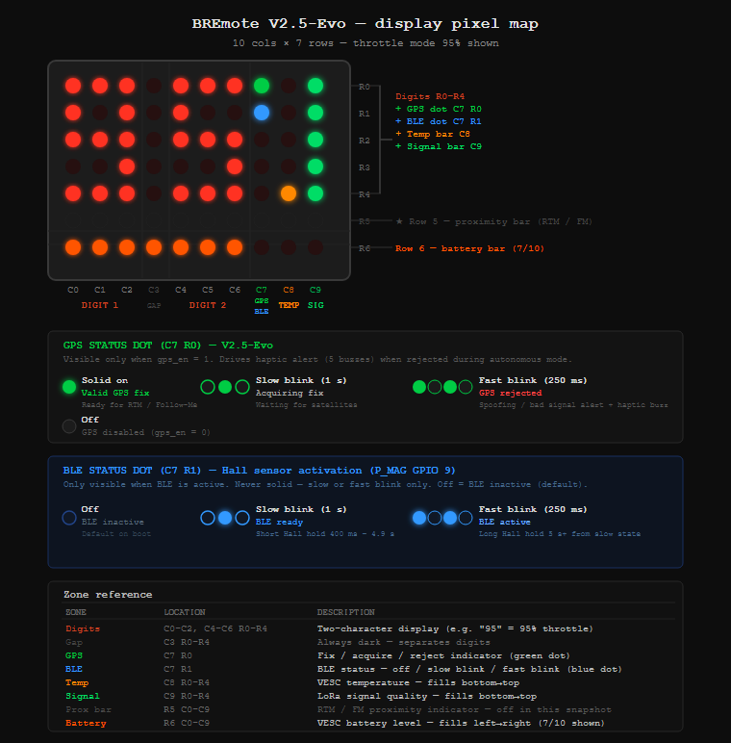
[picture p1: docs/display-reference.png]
BREmote V2.5-Evo Display Reference


*[Full display zone map, font reference, and code details → docs/display-reference.md](docs/display-reference.md)*

### GPS Status Dot (C7 R0)

> 📖 Deeper: [GPS configuration](docs/GPS.md) · [wiring the BN-880](docs/GPS_Wiring_BN880_RX.md) · [troubleshooting](docs/hardware/gps-troubleshooting.md)

Visible only when `gps_en = 1`. Located at the top-right corner of the digit area.

| State | Meaning |
|---|---|
| Solid | **FM-grade fix** — RTM and Follow-Me ready |
| Slow blink (1 s) | Acquiring fix — not yet good enough to steer on |
| Fast blink (250 ms) | GPS rejected — spoofing check failed or signal too poor |
| Off | GPS disabled (`gps_en = 0`) |

> **Solid is a quality gate, not a satellite count.** `txGpsGoodFix()` (`Source/V2_Integration_Tx/GPS.ino`)
> requires **all four**: valid position, valid speed, age under `tx_gps_stale_timeout_ms`, and
> **HDOP ≤ `gps_max_hdop`** (default `200` = HDOP 2.0). Tightened 2026-07-20 so the dot matches the
> gate FM actually publishes on — before that it went solid on a fix FM would still refuse.
> Satellite count is deliberately *not* used: a u-blox module has reported 254 km/h and 4800 m as a
> high-confidence fix on **5–7 satellites at HDOP < 3**.

### BT Status Dot (C7 R1)

> 📖 Deeper: [BLE implementation](docs/BLE_Implementation.md) · [phone-app brief](docs/BLE_App_Brief.md)

Located just below the GPS dot. Driven by `bt_dot_state`, controlled by the DRV5032 Hall sensor hold duration on P_MAG (GPIO 9). BREmote already uses Hall-effect sensors for throttle, toggle, and power switch — this adds a fourth on a free GPIO for magnet-based BLE activation. See the [Hall Sensor Expansion guide](docs/Hall_Sensor_Expansion.md) for wiring and firmware details, or the [install tutorial](docs/Hall_Sensor_Install_Tutorial.md) for step-by-step fitting instructions and hardware options (including easier-to-solder alternatives to the SOT-23 package).

| State | `bt_dot_state` | Meaning |
|---|---|---|
| Off | `BT_DOT_OFF` | BLE inactive |
| Slow blink (1 s on/off) | `BT_DOT_SLOW` | BLE ready — toggled by a short Hall sensor hold (400 ms – 4.9 s) |
| Fast blink (250 ms on/off) | `BT_DOT_FAST` | BLE active — triggered by a long hold (5 s+) from slow state |

Releasing the magnet while `BT_DOT_FAST` → returns to `BT_DOT_OFF`. Short hold while `BT_DOT_SLOW` → toggles back to `BT_DOT_OFF`.

> BLE NUS (Nordic UART Service) is in **master** — field-confirmed ✅ (2026-05-16). The stack advertises as `BRemote-TX-XX` (last byte of BT MAC) and serves live VESC telemetry in VESC Tool binary protocol (auto-detected) or CSV push mode for generic NUS apps. Use **VESC Tool** (iOS/Android, free) — scan, connect to `BRemote-TX-XX`, and live gauges appear immediately: FET Temp, Motor Amps, Duty, Voltage, RPM. Enable via the `bt_enabled` SPIFFS field (0=off, 1=Hall/session default, 2=always on) or force for a single session with the `Throttle + LEFT toggle` boot gesture. **Boot on battery** — USB power blocks BLE init.

### How to Enable BLE

Three ways to activate BLE on the TX — choose whichever fits your use:

| Method | How | Persists |
|---|---|---|
| **SPIFFS config** | Set `bt_enabled` via the Web Serial Config Tool or `?set bt_enabled 2` + `?save` over serial. `0`=always off, `1`=Hall/session mode (see below), `2`=always on (BLE starts 5 s after boot every ride). | Across reboots |
| **Boot gesture** | Hold **Throttle + LEFT toggle** while powering on. BLE activates for that session regardless of `bt_enabled`. Display shows `bt`. | Session only |
| **Hall sensor expansion** ([wiring guide](docs/Hall_Sensor_Expansion.md)) | Connect a DRV5032 to GPIO 9 (P_MAG) — BREmote already uses Hall sensors for throttle, toggle, and power switch; this adds a fourth on a free GPIO. With `bt_enabled=1`: short magnet hold (400 ms – 4.9 s) → BT dot slow blink (BLE ready). Long hold (5 s+) from slow state → BT dot fast blink (BLE active). Short hold again → BLE off. | Until magnet gesture or reboot |

> **Always boot on battery.** Plugging in USB during boot triggers the charger detection loop — `initTasks()` never runs and BLE never starts regardless of which method you use.

Once BLE is active, open **VESC Tool** (iOS or Android, free), scan for `BRemote-TX-XX`, connect, and live gauges appear — FET temp, motor amps, duty, voltage, RPM.

---

### R5 Proximity Bar

Row R5 (just below the digit area, C0–C9) is a proximity indicator during RTM or FM. Blinks 1 s on / 500 ms off.

**RTM bar** — shrinks right-to-left as the buggy approaches:

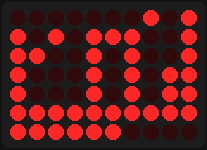
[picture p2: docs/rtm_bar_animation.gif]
RTM Proximity Bar


Full bar (10 pixels) = buggy at arm distance. Shrinks from the right as the buggy closes in. Gone at stop distance just before RTM disengages.

**FM bar** — expands outward from center sweet spot:

| Waiting | Following | Coming to you |
|---|---|---|
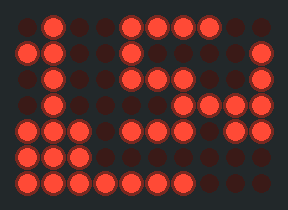
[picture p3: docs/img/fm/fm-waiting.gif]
Waiting
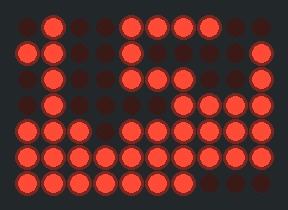
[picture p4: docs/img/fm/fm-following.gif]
Following
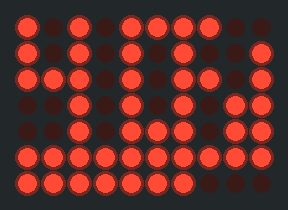
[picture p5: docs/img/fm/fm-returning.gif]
Coming to you
|  |  |  |

*Nightly screens (`fm-stations` branch). Following: the numbers are metres to the buggy and the bar shrinks as it closes in.*

2 pixels at C4–C5 = ideal following distance. Expands symmetrically outward as the buggy lags further behind. 1 pixel = buggy too close.

> See [docs/display-reference.md](docs/display-reference.md) for full implementation details and current FM bar status.

> **Upcoming release:** the bars above show the current master firmware. The new screens add
> indicator dots (one hopping = waiting, two steady = following, filling down = coming to you).
> See the [screens page](https://monterman.github.io/BREmote-V2/followme-screens.html).

---

## Startup Input Combinations

### TX

| Input held at boot | Action |
|---|---|
| LEFT toggle | Calibration mode |
| RIGHT toggle | Pairing mode |
| Throttle + LEFT toggle | Force BLE for session (activates BLE regardless of `bt_enabled` setting) |
| Throttle + RIGHT toggle | Delete SPIFFS config (factory reset) |

### RX

| Input held at boot | Action |
|---|---|
| BIND button | Pairing mode |
| BIND + AUX buttons | Delete config (factory reset) |

---

## Connection Examples

<details>
<summary>VESC with UART — click to expand</summary>

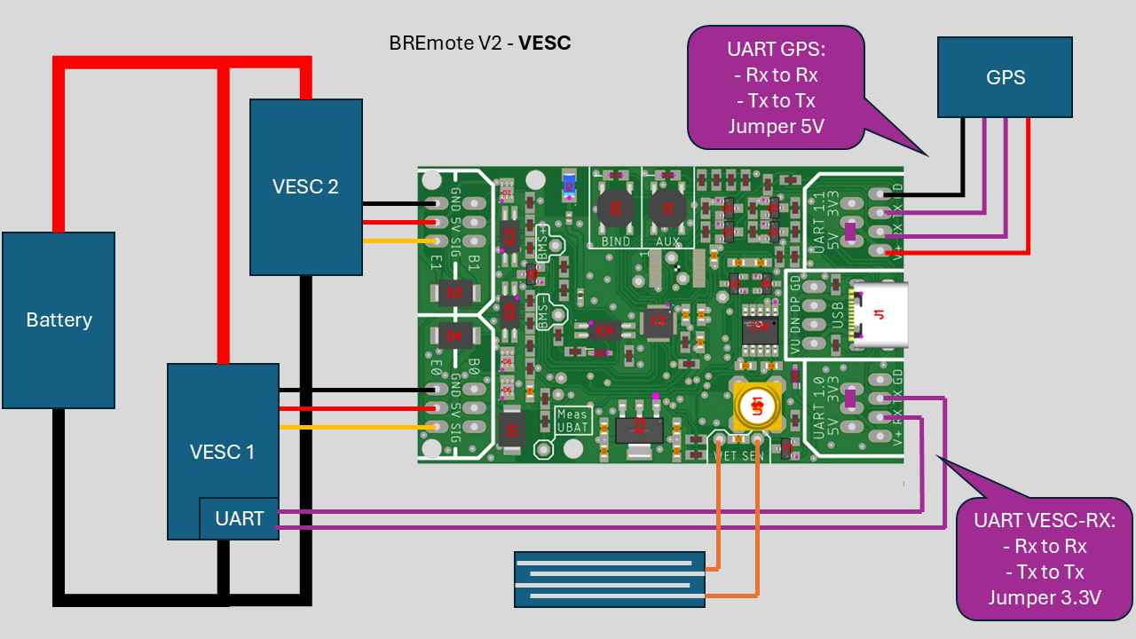
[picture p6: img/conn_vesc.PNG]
VESC with UART


</details>

<details>
<summary>ESC with BREmote BEC — click to expand</summary>

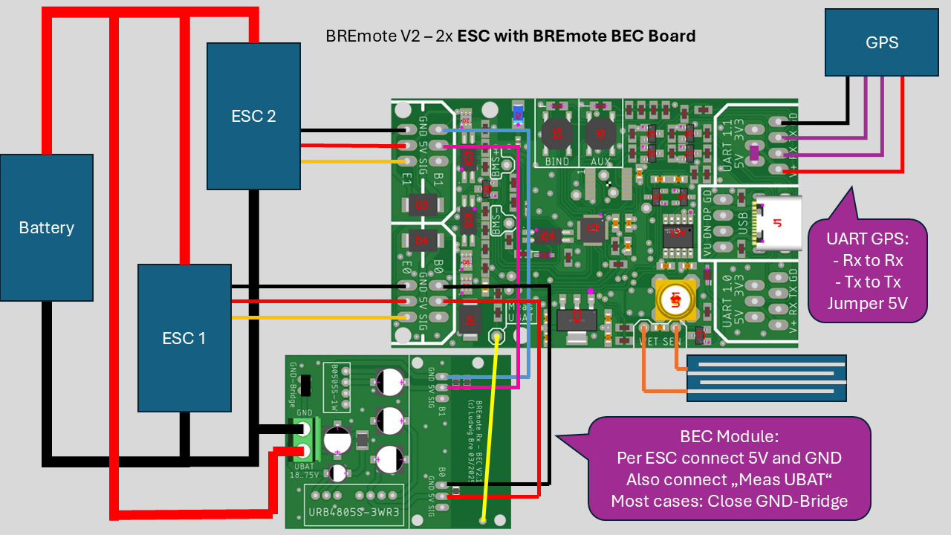
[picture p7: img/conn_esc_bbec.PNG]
ESC with BREmote BEC


</details>

<details>
<summary>ESC with own BEC — click to expand</summary>

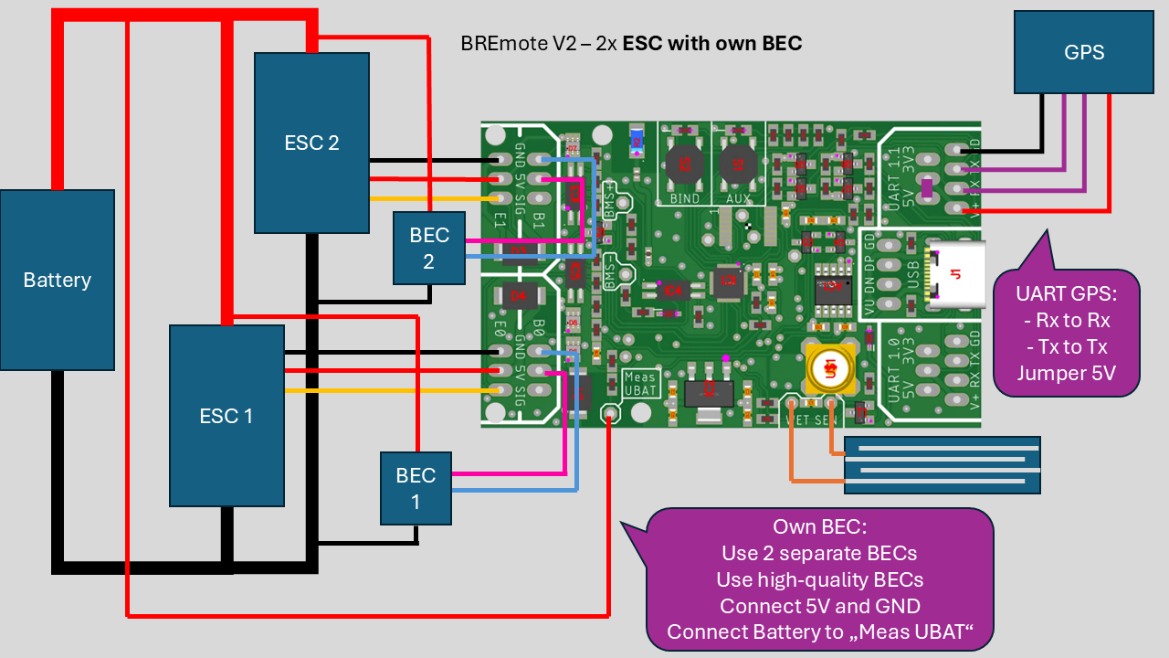
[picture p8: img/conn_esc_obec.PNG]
ESC with own BEC


</details>

<details>
<summary>VESC + Servo — click to expand</summary>

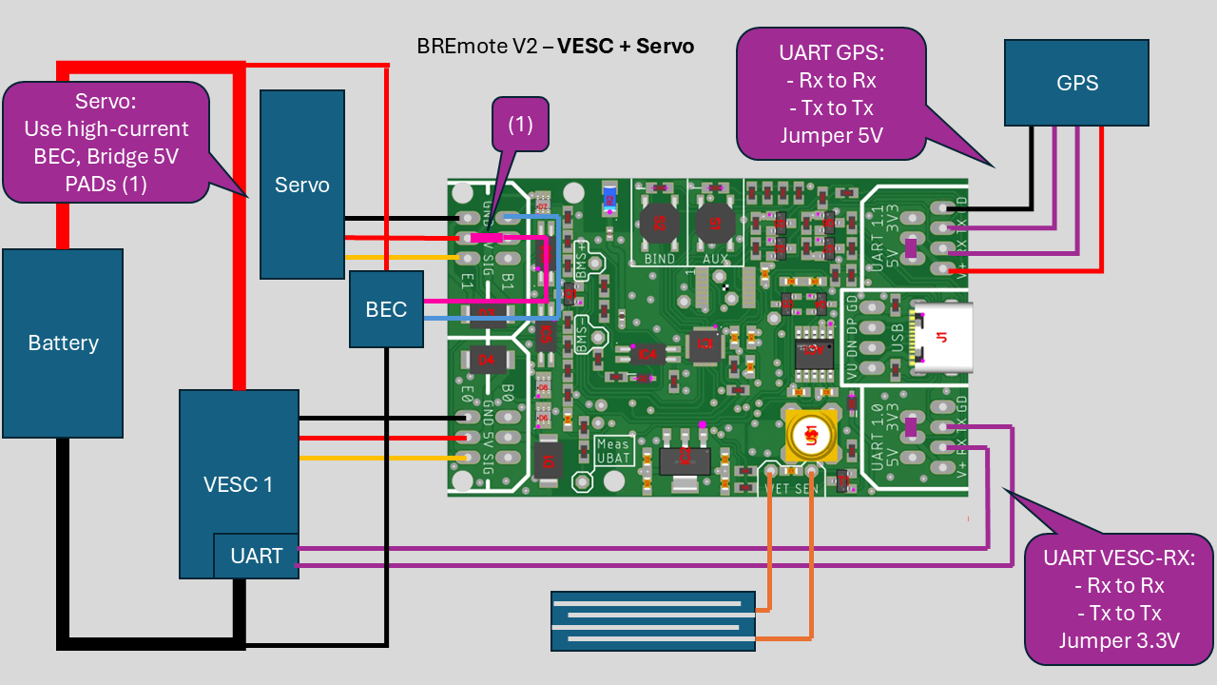
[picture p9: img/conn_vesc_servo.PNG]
VESC + Servo


</details>

<details>
<summary>ESC + Servo — click to expand</summary>

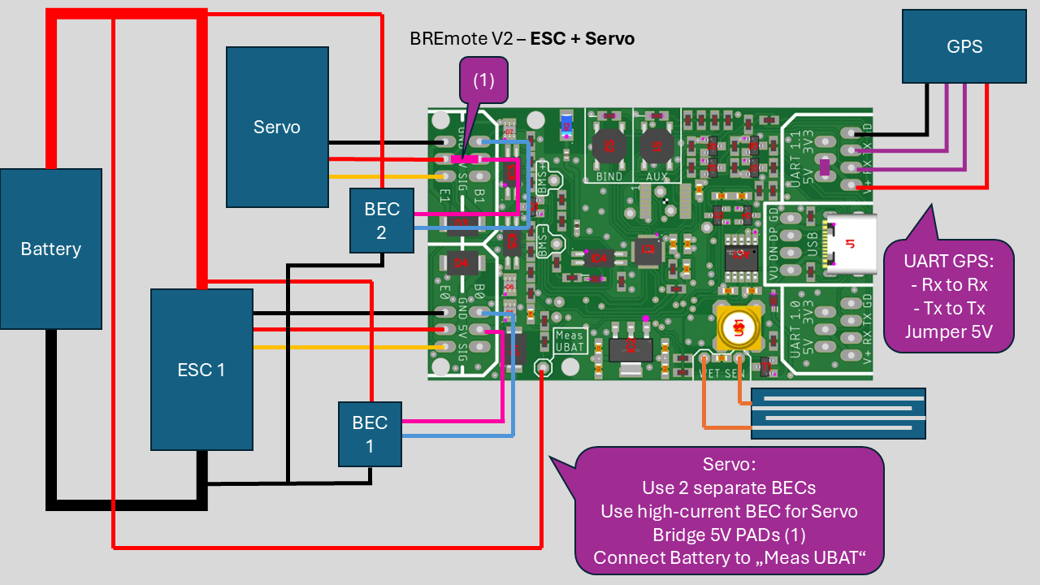
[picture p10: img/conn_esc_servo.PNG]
ESC + Servo


</details>

---

## Alpha Testing Notes

> 📖 Reporting a problem? Use the [Beta testing sheet](docs/Beta_Testing_Sheet.md) so the report is actionable.

BREmote V2.5-Evo is in Alpha. The firmware compiles, has been water tested for control flow and safety gates, and includes anti-spoofing and RTM/FM features. Currently running more water tests to graduate to Beta release.  If you are an alpha tester building on this fork, the project recommends:

- Test in a controlled environment (shallow water, short range, motors disconnected for first dry run, second run with motors on a leashed test stand) before any open-water use.
- Until the compass EMI behavior on your specific hardware is characterized, treat RTM steering as advisory, not autonomous. Keep `rtm_steer_exit_on_input = 1` enabled (any sideways toggle disengages RTM immediately and returns full manual control).
- Manual control must always work even if RTM, FM, GPS, or compass fail. Do not rely on autonomous features as the primary safety path.
- Releasing the throttle trigger always stops the motor — this is the failsafe, and it works regardless of what RTM, FM, or telemetry are doing.

Anyone field-testing this fork should treat each session as data-gathering, not as production use.

### Logging for Tuning

The data logger is the primary tool for validating and tuning the RTM/FM steering controller during early field sessions. The controller ships with five preset values (Very Soft → Very Sharp) that have been chosen analytically; **empirical validation against your specific hardware and water conditions is required** before trusting any preset on the water. A separate steering-tuning guide and a log-analysis web tool are planned for a later development phase. For now, raw CSV logs viewed in any spreadsheet or plotted with Python / gnuplot will surface the patterns that matter.

**How to record a session (briefly — full details in the Data Logger section above):**

- Power on, wait for GPS lock (entries without fix record zero coordinates).
- Press the AUX button once → green LED flashes 5× → logging starts.
- Run your test (RTM walk, FM run, manual ride).
- Press AUX again → green LED flashes 2× → logging stops.
- Pull the file via the embedded WebUI Logs panel or via `?download <filename>` over serial.

**Default logging rate:** 3 Hz (333 ms per sample), set in firmware. Override per session with `?lograte <Hz>` over serial — the argument is **Hz, not milliseconds**. Typical values 10 (10 Hz) down to 1 (1 Hz); fractions work, e.g. `?lograte 0.1`. Lower Hz = smaller files = longer sessions; higher Hz = better resolution for tuning fast oscillation.

**Storage note:** if SPIFFS fills too quickly during long sessions, lower the rate with `?lograte`, **don't trim columns** — every diagnostic field is there to make the controller observable when something goes wrong, and the cost of dropping them is much greater than the storage savings.

**Key columns for steering tuning (full set is 31 columns):**

> The last five — `remote_error`, `effective_steer`, `tx_distance_m`, `rssi_dbm`, `snr_db` — were added in the 2026-07-19 and 2026-07-24 updates. `rssi_dbm` / `snr_db` are the LoRa link quality measured **at the RX for the packets the TX sent**, i.e. the *command* link, which is the direction that matters for control. `-999` / `-99.0` / `-1.0` are the "no data" sentinels.

<details>
<summary><strong>Click to expand: Full log column reference (14 fields with tuning relevance)</strong></summary>

<br>

| Column | Meaning | Why it matters for tuning |
|---|---|---|
| `timestamp_ms` | Time since boot (ms) | X-axis for any plot |
| `speed_kmh` | RX GPS speed (km/h) | Confirms whether buggy is moving fast enough for GPS COG to be primary heading source |
| `latitude` / `longitude` | RX position | Plot the actual path; visual sanity-check |
| `thr_received` | Final throttle command (0–254) | What the user requested vs what RTM allowed |
| `rtm_source` | Heading source picked: 0=GPS COG, 1=GPS COG fresh, 2=compass snapshot, 3=no data | Confirms layered logic chose the right source at each moment |
| `rtm_confidence` | 3=HIGH, 2=MED, 1=LOW, 0=none | Modifier on steering authority |
| `rtm_rx_active` | 1 = RTM engaged, 0 = idle | Mark when RTM is actually doing work |
| `rtm_steer_override` | Final steering output (127 = straight) | What the buggy was told to do |
| `rtm_heading_chosen_dx10` | Heading used for steering (0.1° units) | What the controller used as "current heading" |
| `gps_course_dx10` | Raw GPS COG (0.1° units) | Independent reference for direction-of-travel |
| `compass_live_dx10` | Live compass (0.1° units) | Independent reference; diverges from GPS COG under motor EMI |
| `cog_age_ms_div10` | GPS COG freshness (10 ms units, ≤150 = fresh) | Confirms COG didn't go stale |
| **`heading_error_dx10`** | Bearing-to-target − current-heading (0.1° units; 32767 = no data) | **Primary tuning signal — magnitude and oscillation visible here** |
| **`d_error_dx10`** | Rate-of-change of heading error (0.1°/sec) | **Kd tuning signal — high during settling = need more damping** |
| `motor_current_A`, `voltage_V`, `ERPM` | VESC telemetry | Power/load context; correlates compass EMI with current draw |

The two **bold** columns (`heading_error_dx10`, `d_error_dx10`) were added specifically to make steering tuning data-driven. Plot them over time during an RTM/FM run: sustained ±20–50° wobble at 1–3 Hz means the buggy is snaking and the active preset has too little damping; smooth curves trending to zero mean the controller is working.

</details>

---

## Known Limitations

### Features Still Pending

| Feature | Status |
|---|---|
| Follow-Me full implementation (under testing) | FM override operational; full autonomous follow-me behaviour (positional control loop) implemented |
| BLE telemetry | ✅ **Released in master — field-confirmed 2026-05-16.** NUS + VESC Tool binary protocol (COMM_GET_VALUES auto-detected). Live gauges: Temp, Motor Amps, Voltage, Duty, RPM. Connect with VESC Tool (iOS/Android, free) to `BRemote-TX-XX`. Enable via `bt_enabled` SPIFFS field (0=off, 1=Hall/session, 2=always on) or `Throttle + LEFT toggle` boot gesture. Boot on battery — USB blocks BLE init. |
| RTM/FM hardware field test | Static code review passed (10/10 gates). Outdoor Water test GPS + motor done. |

### Bugs Found and Fixed Between Upstream and V2.5-Evo

> BREmote V2.5-Evo is a fork of Jan's BREmote V2 codebase, which itself extends Ludwig's original BREmote. The architecture decisions (3-byte addressing, CRC8 pairing, semaphore-driven LoRa ISR, the Common engine pattern) are from upstream and are sound. The issues below were uncovered during the V2.5-Evo audit. Some are defects that existed in the upstream regardless of feature set; others only became safety-relevant when V2.5-Evo added concurrent GPS polling, Phase A anti-spoofing, RTM, and FM, which significantly increased the loop-task workload.

<details>
<summary><strong>Click to expand the full bug list (7 issues fixed)</strong></summary>

<br>

| # | Issue | V2.5-Evo file:line | Note | Fix |
|---|---|---|---|---|
| 1 | Watchdog 1000ms timeout | `Source/V2_Integration_Rx/Init.ino:52-58` | Adequate for upstream feature set; insufficient under V2.5-Evo combined GPS (~300ms) + wetness (~300ms) + VESC (~210ms) load (~810ms peak, ~190ms margin). | Raised to 3000ms with full load math in source comment. |
| 2 | `vesc_struct` cross-core race | `Source/V2_Integration_Rx/VESC.ino`, `Logger.ino` | `vesc` written on core 1, read on core 0; no synchronization. Defect existed upstream; harder to hit there because Logger ran less aggressively. | Added `vescMutex` semaphore, 50ms take timeout on both readers and writer. |
| 3 | `logging_active` non-volatile flag | `Source/V2_Integration_Rx/Logger.ino` | Compiler-cached value across cores; flag toggle from one core not always seen by the other. | Declared `volatile`. |
| 4 | `ensureFreeSpace()` could delete the active log file | `Source/V2_Integration_Rx/Logger.ino` | Free-space loop iterated all `.log` files including the one currently being written. | Active log file path now excluded from deletion candidates. |
| 5 | `readBCFromSPIFFS()` heap out-of-bounds | `Source/V2_Integration_Rx/SPIFFS.ino` | Decoded payload < 102 bytes overran a fixed-size struct copy. | Length check added: `decodedLen < 102` rejects short files. |
| 6 | `triggeredReceive` and `generatePWM` 2048-byte stacks | `Source/V2_Integration_Rx/Init.ino:41-43` | Stack size adequate for upstream; tight under V2.5-Evo with RadioLib SX1262 path + RMT driver + Phase A + meta-packet decoding. | Raised to 4096 / 4096 / 3072. Use `?printtasks` to monitor high-water marks. |
| 7 | `scanI2C()` re-initialized Wire mid-runtime | `Source/V2_Integration_Rx/System.ino:157-196` | Function inherited from upstream; `Wire.begin()` inside the scan reset I2C and could glitch in-progress AW9523 traffic. | Removed redundant `Wire.begin()`; Wire is now only initialized once in `initHardware()`. |

</details>

### Compass EMI Load Test — `?magtest`

**This is a BUCKET / DOCK TEST. The motor must be under real load. Do not run it free-spinning.**

`?magtest` measures how much motor current pulls your magnetometer off true. It streams CSV at
10 Hz (millis, mag X/Y/Z, magnitude, heading, VESC ERPM, motor current, throttle) for up to 120 s
and then **prints a verdict** — it no longer leaves you to interpret 1200 rows yourself.

#### Why the load matters more than anything else here

The same buggy was measured twice:

| How it was run | Reported error |
|---|---|
| Bench, prop **free-spinning** | +3 to +5° steady |
| Bucket, prop **under real load** | **87–101°** |

**Seven times worse under load.** A free-spinning prop draws almost no current, so it reads clean
on a compass that is 100° out in the water. The free-spinning result is what originally supported
"relocation is not urgent" — it was wrong, and the conclusion stood for weeks.

`?magtest` now **refuses to grade a run whose peak current stayed under 5 A** rather than
reporting a meaningless number.

#### How to run it

1. Prop in a **bucket of water**, or held against the dock/ground — something that makes it pull
   real current.
2. Leave the throttle at **zero for ~5 seconds**. This sets the motor-off baseline.
3. Bring the throttle **up slowly**, holding at several levels so each current band gets samples.
4. Read the verdict at the end.

#### Reading the verdict

| Worst error under load | Verdict | What it means |
|---|---|---|
| **< 10°** | GOOD | Usable as a live heading, not just the motor-off snapshot. |
| **10–30°** | DEGRADED | Steering is unaffected — the firmware only reads the compass with the motor off — but the compass-vs-GPS cross-check still cannot run during a ride. |
| **> 30°** | USELESS UNDER POWER | Trustworthy only at zero throttle. Move the module. |

One measured detail worth knowing: in that 87–101° dataset the error **did not scale with
current.** It was already 87° at 5–15 A — ordinary cruise — and only reached 101° at 40 A. It
**saturates**, because the interference is already far stronger than the earth's field at the
first few amps, so the needle stops measuring the earth and starts pointing at the motor.

**That makes this a geometry problem, not a current problem.** It cannot be fixed by riding
gently, and it cannot be fixed by calibration — calibration removes *fixed* errors, and this one
changes with throttle, so there is nothing steady to cancel out. **Distance and wire routing are
the only levers.**

#### Where to mount the module

- **As far from the phase wires and battery cables as you can get it.** Two inches makes a huge
  difference at close range.
- **Never over a loop or U-turn in the phase wires.** This is the single worst position and it is
  easy to create by accident. Out-and-back wires cancel each other's field *at a distance*, but at
  the centre of the loop they **add**, and a current loop behaves like a magnet whose field there
  is far stronger than a straight wire at the same spacing. If the module sits above where the
  phase wires turn back on themselves, move it before you change anything else.
- **Twist the phase wires into a tight bundle.** Paired conductors cancel, and the leftover field
  then falls away much faster with distance than a single wire's does. This can buy more than the
  relocation itself.
- **Mount it square to the nose** — see the compass mounting section. Squareness and EMI are
  separate problems with separate fixes; you generally want both.
- After moving it, **re-run `?compasscal`**, then re-run this test to confirm the improvement.

---

## RX Serial Diagnostic Commands

Connect to the RX at 115200 baud. All commands are prefixed with `?`.

| Command | Description |
|---|---|
| `?conf` | Print current RX config (all SPIFFS fields and their live values) |
| `?vescping` | Send a single VESC status request and print the parsed response — confirms the UART link is alive |
| `?vescraw` | Send a correctly-framed `COMM_GET_VALUES` probe (`02 01 04 40 84 03`) and dump the raw reply bytes — use when `?vescping` returns no data to diagnose framing issues. *(The probe CRC was fixed in V2.5.12; before that this command hardcoded a bad CRC and always printed "NO BYTES" even against a healthy VESC.)* |
| `?logstat` | Print SPIFFS log storage statistics — file count, total bytes used, bytes free |
| `?lograte <Hz>` | Override logging rate per session. **Argument is Hz.** Example: `?lograte 10` = 10 Hz, `?lograte 0.1` = one sample per 10 s. Change is RAM-only; resets on reboot. |
| `?deletelog <filename>` | Delete a specific log file from SPIFFS. Use `?list` to see filenames first. |
| `?deleteallogs` | Delete all log files from SPIFFS (skips the currently active log if logging is running) |
| `?list` | List all log files on SPIFFS with sizes |
| `?download <filename>` | Stream a log file as raw CSV over serial |
| `?start` / `?stop` | Start or stop the data logger (same as AUX button) |
| `?compassheading` | Stream live compass heading (degrees) at 10 Hz — useful for verifying QMC5883L orientation and EMI influence |
| `?printcompass` | Print a single raw compass reading (X/Y/Z counts) — quick sanity check without streaming |
| `?magtest` | **Bucket/dock EMI test + verdict.** Streams CSV (mag X/Y/Z, heading, VESC ERPM, motor current, throttle) at 10 Hz for up to 120 s, then grades the result. ⚠️ **The motor MUST be under load** — a free-spinning run reads clean on a compass that is 100° out. Refuses to grade below 5 A peak. See the Compass EMI Load Test section above |
| `?compasscal` | Run the 45 s compass calibration. **Nose on NORTH → two full CLOCKWISE circles → finish on north.** Sets the iron calibration, the mounting handedness and the mounting orientation in one run. BIND LED: 2 = full success, 3 = PARTIAL (orientation not updated — walk it again), 10 = nothing saved |
| `?magalign` | Re-derive the compass **mounting orientation only** — point the nose at north, hold steady, 5 s average. Needs an existing iron calibration; cannot detect a mirrored module |
| `?printrssi` | Print current LoRa RSSI and SNR |
| `?printtasks` | Print FreeRTOS task stack high-water marks — use to verify stack headroom after tuning |
| `?printgps` | Print current RX GPS fix (lat, lon, speed, fix type) |
| `?printbat` | Print RX battery voltage reading |

## TX Serial Diagnostic Commands

Connect to the TX at 115200 baud. All commands are prefixed with `?`.

| Command | Args | Description |
|---|---|---|
| `?conf` | | Print TX config info and current `usrConf` values |
| `?get` | `<key>` | Get a single config field by name |
| `?set` | `<key> <value>` | Set a config field in RAM (use `?save` to persist) |
| `?save` | | Persist current RAM config to SPIFFS |
| `?keys` | | List all config field names |
| `?state` | `[json]` | Subsystem state overview |
| `?printrssi` | `[json]` | Stream live RSSI/SNR (type `quit` to stop) |
| `?printinputs` | `[json]` | Stream live input values — throttle, toggles, Hall sensor (type `quit` to stop) |
| `?printtasks` | `[json]` | FreeRTOS task stack high-water marks |
| `?printpackets` | | TX/RX packet counts |
| `?printgps` | | TX GPS state and current fix status |
| `?gpsraw` | `[sec]` | Dump raw NMEA output from GPS module (default 5 s, type `quit` to abort) |
| `?gpsreinit` | | Re-run `initTxGPS()` without rebooting — useful after cable swap |
| `?gpscoldreset` | | Send UBX-CFG-RST cold-restart to GPS module (clears all cached satellite data) |
| `?wifiver` | | Print embedded web UI version info |
| `?wifiupd` | | Force web UI update to SPIFFS |

---

## Links

- [Original BREmote V2 repository — Luddi96](https://github.com/Luddi96/BREmote)
- [Web Serial Config Tool — open in browser](https://monterman.github.io/BREmote-V2/BREmote_V2.5-Evo_Web_Serial_Config_Tool.html) *(Chrome/Edge — no download needed)*
- [Web Serial Config Tool — offline download](docs/BREmote_V2.5-Evo_Web_Serial_Config_Tool.html)
- [RTM Design Document — DESIGN_RETURN_TO_ME.md](DESIGN_RETURN_TO_ME.md)
- [FM Autonomous-Following Design Document — DESIGN_FOLLOW_ME.md](DESIGN_FOLLOW_ME.md) *(design spec — implemented in this release, alpha)*
- [Config Tool — lbre.de](https://lbre.de) *(LudwigBre's original web config tool)*
- [Build Video](https://github.com/Luddi96/BREmote) — see original Luddi96 repository
- [SW Setup / Config Video](https://github.com/Luddi96/BREmote) — see original Luddi96 repository
- [Flash Download Tool](https://github.com/Luddi96/BREmote)
- [Expo Tool](https://github.com/Luddi96/BREmote)
- [LUT Creation Tool](https://github.com/Luddi96/BREmote)
- [Plot Digitizer](https://github.com/Luddi96/BREmote)

---

## Changelog

### V2.5.12 — July 2026 *(monterman)* — VESC Telemetry Restored, FM Mode Mapping Canonicalized, Tunable Arm-Hold

- **VESC telemetry restored — the long-standing "no telemetry" issue was a wrong CRC in the `?vescraw` diagnostic; the actual telemetry path was always correct.** The `?vescraw` command hardcoded the wrong CRC16 (`0x4007`) on its `COMM_GET_VALUES` probe. The correct value is `0x4084` — CRC16-CCITT/XMODEM (poly `0x1021`, init 0) over payload `{0x04}`. A VESC silently discards any bad-CRC packet and never replies at any baud, so `?vescraw` always printed "NO BYTES" even against a perfectly healthy VESC — a false negative that masked good hardware and sent the diagnosis chasing the VESC, RX, AW9523 MUX, cables, and firmware when none of them were at fault. Bench-proven over an FTDI on **both VESC FW 6.05 and 6.06**: the correct frame `02 01 04 40 84 03` returns a full GET_VALUES reply (live 39.5 V / 26.7 °C). The real telemetry path (`getValuesSelective` → `sendToVESC` → `vesc_crc16`) was always correct — only the `?vescraw` diagnostic frame was wrong.
- **In-ride telemetry unfroze (RX):** removed a throttle-skip gate that skipped the VESC poll while throttle ≥ 25. On a continuous-throttle vehicle (tow buggy) that meant `getVescLoop()` never ran once you were on the trigger, freezing telemetry to dashes for the whole ride. Reverted to the SW55 unconditional 2 Hz poll; the MUX-EMI concern the gate targeted is already covered by the read-back-verify in `setUartMux()`.
- **FM mode mapping canonicalized to `1 = Near-Right, 2 = Behind, 3 = Near-Left` (RX):** RX comments and web-UI labels were relabeled to match the TX convention already used on the display, in the TX web UI, and in this README. Both boards ship `defaultConf.followme_mode = 2` (Behind — the defensive FM geometry); every surface (web UI `def:`, HTML tool, README, guide) now states the default as **2 (Behind)**. The `foiler_low_speed` default text was corrected `5 → 8` km/h to match `defaultConf`. Labels and defaults only — no control-logic change, no confStruct / SW_VERSION change.
- **TX arm-hold now tunable:** `rtm_hold_duration_s` (RTM LEFT-hold) and `fm_hold_duration_s` (FM RIGHT-hold) are now live SPIFFS fields, configurable 4–10 s. Both were previously hardcoded to 5 s and labeled "reserved" in the web UI. Default stays 5 s. No confStruct / SW_VERSION change.
- **`DESIGN_FOLLOW_ME.md` added:** the design spec for FM autonomous following (state machine, activation gates, target-point math, throttle cap chain). **FM autonomous following is implemented in this release.** Selecting an FM mode (F0–F3) cycles and stores the mode and makes the buggy follow the rider.
- **No confStruct changes; SW_VERSION unchanged (TX/RX).**

---

### V2.5.11 — July 2026 *(monterman)* — Collision Backoff, RX Radio Self-Heal, No-OTA Partition & 3 Hz Logger

- **Feature A — adaptive RF collision backoff (TX `sendData()`):** two remotes sharing the same RF preset no longer stay locked in a colliding timeslot. On a missed telemetry reply the TX adds slot-jitter that permanently phase-shifts it into a different slot, and after 3 consecutive misses the base cadence drops 100 ms → 200 ms, recovering to 100 ms after ~50 s of clean replies. *Upstream collision-detection mechanism by LudwigBre (2.2.7)* — adapted for this fork: variable send cadence, the GPS meta-packet ≥2 Hz floor is preserved by gating the backoff off while Follow-Me/RTM is active, and the jitter PRNG is seeded per-unit from `own_address` so identical units actually de-correlate.
- **Feature C — RX SX1262 self-heal:** the RX `triggeredReceive()` semaphore-timeout branch now re-arms the radio (`implicitHeader(6)` + `startReceive()`). Previously a wedged SX1262 or a dropped DIO interrupt left the link dead until a power-cycle; now it recovers on its own after 2 s of silence. Motor-safe — runs only when the link is already down and the failsafe has zeroed throttle.
- **Logger default 5 Hz → 3 Hz:** better suited to propeller / max-speed testing and stretches on-board session capacity. Raise to 5 Hz at runtime for RTM/steering analysis with `?lograte 5` over serial (resets to the 3 Hz default on reboot; the rate is not persisted). Record size, rate→duration table, and capacity guidance: see `docs/LOGGER_NOTES.md`.
- **Custom no-OTA partition (RX):** OTA is intentionally dropped (RX is flashed over USB), reclaiming the second app slot for a single 2.0 MB app + 1.875 MB SPIFFS layout (`Source/V2_Integration_Rx/partitions.csv`). Gives ~809 KB of app headroom for Follow-Me work and a larger SPIFFS than before for longer logging. First flash after the partition change reformats SPIFFS → RX settings reset and compass re-cal required (binding survives).
- **No confStruct changes; SW_VERSION unchanged (TX/RX).** TX compiles at 39% of the huge_app slot; RX at 60% of the new 2.0 MB app slot.

---

### SW56–SW58 — May 2026 *(monterman)* — BLE Live Telemetry Released to Master

**BLE feature merged from `feature/bluetooth` → `master` — field-confirmed ✅ (2026-05-16):**

- **NUS + VESC binary protocol:** TX advertises `BRemote-TX-XX` (last byte of BT MAC). Connect with VESC Tool (iOS/Android, free) and get live gauges — FET temp, motor amps, duty cycle, battery voltage, RPM — sourced from whatever the LoRa link is carrying from the foil.
- **Auto-detect mode:** First `COMM_GET_VALUES` request → VESC protocol mode (app-driven). No request within 500 ms → CSV push mode (generic NUS serial apps).
- **`bt_enabled` SPIFFS config:** 0=always off, 1=Hall-sensor/session mode, 2=always on after 5s boot. Boot gesture: `Throttle + LEFT toggle` forces BLE for the session.
- **BT dot display (C7 R1):** Slow blink = BLE ready, Fast blink = BLE active.
- **Advertisement fix:** NUS UUID in main advert (21 B, fits BLE 31-byte limit); device name in scan response — UUID scan filters work correctly in VESC Tool and Floaty.
- **Expanded LoRa packet 8→19 bytes:** `foil_voltage`, `foil_duty`, `foil_erpm_hi/lo` now carried over LoRa from RX, decoded by TX and served via BLE.
- **Dependency:** NimBLE-Arduino 2.x (install via Arduino Library Manager).
- **Boot note:** Always boot on battery for BLE — USB-C power triggers `checkCharger()` and blocks `initTasks()`.

---

### SW51–SW55 — May 2026 *(monterman)* — VESC Telemetry Fix, Display Polish, RTM Bench-Complete

**VESC telemetry — root cause confirmed and fixed:**
- **Primary root cause:** USB-C serial cable on GPIO 18/19 silences VESC UART during field use — ESP32-C3 native USB D−/D+ shares these pins with Serial1. Operational fix: unplug USB-C during field use.
- **SW55:** GPS MUX not yielding — `getGPSLoop()` and `configureGPS()` now call `setUartMux(0)` on return. GPS always has priority on the UART MUX; always yields the bus back to VESC when done.
- **SW55:** `rcv_err` flag persistence bug removed — one stray byte poisoned the full 200 ms receive window. CRC handles frame validation; the flag was redundant and harmful.
- **SW55:** Boot MUX state — `configureGPS()` now ends with `setUartMux(0)` so boot starts with the MUX on the VESC channel.
- **SW54:** MUX retry loops reverted — rapid I2C writes to AW9523 caused bus corruption (GPS chars=0, VESC zero packets).

**Display improvements:**
- **SW53:** `unlockAnimation()` rewritten — 3-frame paintbrush sweep R0→R6; each row stays lit as the arrow descends (`|=` without inter-frame clear); R4–R6 outer columns fully painted; boot delay 3 s → 500 ms.
- **SW55:** Boot timing refined — VI display 250 ms, voltage display 1450 ms; padlock appears at ~4.5 s total boot.

**New features:**
- **DISPLAY_MODE_INTBAT:** 7th TX display mode — shows TX internal LiPo voltage (UB label, C7 R1 BT dot co-located). Cycle: TEMP → THR → SPEED → POWER → AMP → UBat → BAT.
- **LATEST header convention:** Single `// *** LATEST: ... ***` line at top of both integration `.ino` files shows current SW version at a glance.

Compiled clean: TX 39% / RX 40% flash (huge_app). SW_VERSION unchanged: TX=26, RX=31 (no confStruct changes).

---

### V2.5.08 — April 2026 *(monterman)* — Display, Gesture & UX Overhaul

- **Gesture redesign (breaking):** LEFT hold 2s = lock/unlock the remote; RIGHT hold 2s = cycle display; RIGHT tap→LEFT hold 5s = RTM arm; LEFT tap→RIGHT hold 5s = FM cycle. The remote boots **locked** by default (SPIFFS); LEFT-hold 2s locks/unlocks — kept for safety.
- **RTM arm/disarm display:** static `rn` ×2 (3s total), replaces scrolling `rtn`
- **FM mode display:** `F0`/`F1`/`F2`/`F3` instead of named abbreviations
- **RTM/FM active info display:** TX shows distance-to-TX or speed on dot matrix while RTM/FM active; `rtm_display_mode` configures mode (0=distance, 1=speed, 2=alternating 2.5s); distance shown as `X.X` m below 10m with C3 decimal dot, `XX` m above
- **RX→TX distance telemetry:** RX computes and encodes distance into `telemetry.rtm_distance` (TelemetryPacket index 5); TX decodes for display
- **Vibration Pattern 4:** 2×80ms fast short pulses for RTM arm/disarm confirmation
- **RTM steer exit gate:** steering input exits RTM when `rtm_steer_exit_on_input=1` (default)
- **`rtm_max_runtime_s` default 120→0** (0=disabled; safety gates handle all real scenarios)
- **`displayDigits()` clamp bug fixed:** clamp raised 29→33; LET_R/LET_N/LET_S/LET_M now display correctly (was silently rendering as blank)
- **Unlock animation 2× faster:** ANIMATION_DELAY 80ms→40ms
- **ET error handler:** remote_error=20 (LET_T) shows `--` and auto-clears after 3s; no vibration
- **3 new TX SPIFFS fields:** `rtm_display_mode`, `fm_warn_distance_m`, `rtm_steer_exit_on_input`
- **TelemetryPacket grows:** `rtm_distance` added at index 5; `link_quality` moved to index 6 (sizeof 6→7); TX+RX bounds-check auto-adapts
- **confStruct sizeof:** TX 120→126, RX unchanged. First P8 flash resets TX settings to defaults.

<details>
<summary><strong>Click to expand: Older changelog entries (V2.5.10, V2.5.09, V2.5.01, V2.x)</strong></summary>

<br>

### V2.5.10 — April 2026 *(monterman)* — R5 Proximity Bar, Distance Units, Full-Screen Messages

- **R5 proximity bar:** Row R5 (C0–C9) lights as proximity indicator during RTM and FM. Blinks 1 s on / 500 ms off.
  - RTM bar: square-root shrink curve, full at arm distance, gone at hard stop (C0→C9 left-fill, shrinks from right)
  - FM bar: linear fill (placeholder — center-expanding from C4–C5 intended; separate future change)
- **Distance unit display:** `dist_unit` SPIFFS param — 0=metres/km, 1=feet/miles. All distance math stays in metres; conversion is display-layer only. No sizeof change (fills tail padding).
- **Stop display:** RTM exit now shows `St` in large-font (`displayDigits(LET_S, LET_T)`) for 2 s. Arm confirm is unlock animation + `rn` blink. Compact-font full-screen messages for stop and arm were introduced then replaced by large-font `St` in the same P9 cycle (Bug4/Chg5 in RTMState.ino).
- **`FM 0`–`FM 3` and `E 7`** still use compact 3×7 full-screen font. (Error code E71 — display renders as `E 7` due to screen width.)
- **Old scrolling `Stp`** (scroll3Digits LET_S LET_T LET_P) removed.
- **FM proximity warning vibration:** TX fires 2×Pattern-2 burst when TX-RX distance drops below `fm_warn_distance_m` (default 150 m).
- **`dist_unit` new TX SPIFFS field.** No sizeof change.

### V2.5.09 — April 2026 *(monterman)* — Stability, GPS Hz, Approach Zone

- **Gate 9 clean disengagement:** RTM hard stop is now a clean handoff to manual — no emergency stop, no display glitch. Throttle ramps to 0 in approach zone then disengages seamlessly.
- **RTM re-arm fix:** Non-zero sentinel (0xFF) used when RTM inactive — zero-init throttle no longer falsely passes arm guard.
- **Approach decel zone:** `rtm_approach_zone_m` (default 15 m) — linear throttle ramp to 0 begins this many metres before the hard stop distance.
- **GPS non-blocking:** GPS polling restructured to avoid stalling the 10 Hz LoRa cycle. `gps_update_hz` SPIFFS param controls update rate (default 2 Hz; 5 Hz recommended for RTM direction tuning, but uses more bandwidth).
- **`vesc_timeout_s` SPIFFS param:** VESC "not available" timeout configurable (was hardcoded 20 s).
- **`radio_preset` capped at 2:** Value 3 caused `radioErrorHalt` on boot; max now enforced in ConfigService.
- **startTransmit() errors now logged:** Return value was silently discarded; now printed to serial on failure.
- **`gps_max_teleport_kmh` default 200→80:** 80 km/h = 2× craft max speed (was unrealistically permissive).
- **3 new TX SPIFFS fields:** `rtm_approach_zone_m`, `gps_update_hz`, `vesc_timeout_s`.
- **RX confStruct sizeof:** 156→160 (approach zone field + alignment pad). First P8.4 flash resets all RX settings to defaults — re-pair, re-configure, re-run `?compasscal`.

### V2.5.01 — April 2026 *(monterman)*

- Fork established as BREmote V2.5-Evo
- Full codebase audit completed — 7 critical bugs and 10 important issues documented
- TX GPS reading implemented: Beitian BN-220 on Serial1 GPIO 18/19, UBX binary init (115200 baud, 5 Hz), non-blocking polling — does not stall the 10 Hz LoRa cycle
- GPS speed display in km/h, knots, and mph via `speed_src` SPIFFS parameter (values 2, 3, 5)
- All user parameters SPIFFS-configurable via the Web Serial Config Tool — nothing hardcoded
- Web Serial Config Tool created (offline HTML, no install required)
- `DESIGN_RETURN_TO_ME.md` added — RTM mode fully designed with state machines, safety gates, and SPIFFS parameter table
- LoRa meta-packet protocol designed: opcodes 0xF1–0xFE reserved for V2.5-Evo autonomous assist features
- SW_VERSION bumped to 3
- `project notes` added for development conventions and standing safety rules

### V2.x — *(Janrusher / LudwigBre releases)*

*Full V2 changelog in the original [Luddi96/BREmote](https://github.com/Luddi96/BREmote) repository.*

Key V2 milestones:
- Dynamic throttle cap mode and Web Console (Janrusher, forked from LudwigBre)
- GPS framework, follow-me skeleton, data logger foundation (Janrusher / LudwigBre)
- Initial release: LoRa link, VESC UART, servo steering, gears, water ingress, expo curve (LudwigBre)

</details>

---

## Credits

| Contributor | Role |
|---|---|
| **[LudwigBre / Luddi96](https://github.com/Luddi96/BREmote)** | Original hardware design, original firmware architecture, project founder, and dev-logger framework (dev-logger branch). All core features originate here. GPL 3.0 author. |
| **Janrusher** | Dynamic throttle cap mode and Web Console foundation — major V2 enhancements forked from LudwigBre, further refined in V2.5-Evo. |
| **monterman** | BREmote V2.5-Evo — TX GPS implementation, dev-logger AUX button toggle with LED status feedback (5× flash = start, 2× flash = stop), date format DDMMYY → MMDDYY, web console major rebuild (upload/download/compare JSON, integrated serial console, TX+RX coverage, plain-English parameter docs for every setting), deep codebase analysis, critical bug documentation, RTM/FM mode design, VESC UART telemetry diagnosis and root-cause fix (SW55), DISPLAY_MODE_INTBAT 7th display mode, BT status dot + Hall sensor activation framework, BLE NUS + VESC Tool binary protocol (COMM_GET_VALUES live gauges — field-confirmed 2026-05-16). |

## ☕ Support the project

If BREmote is useful to you, you can support the work on **[Ko-fi](https://ko-fi.com/monterman)**.

**License:** GNU General Public License v3.0 — same as the original BREmote. See LICENSE file.

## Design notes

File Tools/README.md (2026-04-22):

# BREmote V2 Hardware Test Suite

Windows application for automated testing of BREmote TX and RX units.

## Features

- **Auto-detection**: Scans all COM ports and identifies BREmote devices
- **Device identification**: Automatically distinguishes TX (Transmitter) from RX (Receiver)
- **Automated tests**: Radio, display, sensors, interfaces (no user interaction needed)
- **Interactive tests**: User-guided tests with prompts to move throttle/press buttons
- **Radio link test**: End-to-end test matching TX output with RX input
- **JSON reports**: Exportable test results with timestamps and detailed results
- **GUI & CLI modes**: Interactive GUI or command-line operation

## Installation

```bash
# Install dependencies
pip install -r requirements.txt
```

## Usage

### GUI Mode (Recommended)

```bash
python bremote_test.py --gui
```

**GUI Buttons:**
- **🔍 Scan Ports**: Detects all connected BREmote devices
- **▶ Run Auto Tests**: Automated tests without user interaction
- **👤 Interactive Test**: Guided tests requiring user actions
- **🔗 Radio Link Test**: Tests TX→RX communication (requires both)
- **📄 Save Report**: Exports results to JSON file
- **🗑 Clear**: Clears the log window

### CLI Mode - Scan Only

```bash
python bremote_test.py --scan
```

### CLI Mode - Auto Test All Devices

```bash
python bremote_test.py
```

### CLI Mode - Interactive Tests

Prompts user to perform actions (move throttle, press buttons):

```bash
python bremote_test.py --interactive
# or
python bremote_test.py -i
```

**Interactive Tests for TX:**
- Center throttle position
- Full throttle forward
- Full brake
- Left toggle press
- Right toggle press
- USB mode combo (throttle + left toggle)

**Interactive Tests for RX:**
- VESC detection
- Radio reception
- PWM output (optional, with safety warning)

### CLI Mode - Radio Link Test

Tests the radio link between TX and RX by comparing TX output with RX received values:

```bash
# Default 10 second test
python bremote_test.py --link

# Custom duration
python bremote_test.py --link --duration 30
```

**Radio Link Metrics:**
- Packet loss percentage
- Value matching (throttle/steering differences)
- RSSI (signal strength)
- SNR (signal quality)
- Matched sample pairs

### CLI Mode - Test Specific Port

```bash
python bremote_test.py --port COM3
```

### CLI Mode - Save Report

```bash
python bremote_test.py --report test_results.json
```

### CLI Mode - Verbose Output

```bash
python bremote_test.py -v
```

## Test Coverage

### Automated Tests (TX)

| Test | Description | Commands Used |
|---|---|---|
| Radio TX | Verifies LoRa transmission | `?printPackets` |
| Display | Checks LED matrix interface | `?conf` |
| Hall Sensors | Throttle and toggle inputs | `?printInputs` |
| Analog | Battery voltage monitoring | `?conf` |
| RSSI | Signal strength monitoring | `?printRSSI` |
| SPIFFS | Configuration storage | `?conf` |

### Automated Tests (RX)

| Test | Description | Commands Used |
|---|---|---|
| Radio RX | Verifies LoRa reception | `?packets` |
| VESC | Motor controller interface | `?vesc` |
| PWM | Motor speed PWM output | `?pwm` |
| SPIFFS | Configuration storage | `?conf` |

### Interactive Tests (TX)

| Test | User Action | Verification |
|---|---|---|
| thr_center | Move throttle to center | Value 120-135 |
| thr_max | Full throttle forward | Value ≥200 |
| thr_min | Full brake | Value ≤55 |
| toggle_left | Press left toggle | Toggle state ON |
| toggle_right | Press right toggle | Toggle state ON |
| combo_usb | Throttle + left toggle | Both active |

### Interactive Tests (RX)

| Test | User Action | Verification |
|---|---|---|
| vesc_detect | Ensure VESC powered | VESC detected |
| radio_rx | Press TX buttons | Packets received |
| pwm_output | *(Optional)* | PWM active |

### Radio Link Test

| Metric | Description | Pass Criteria |
|---|---|---|
| packet_loss | % of lost packets | <20% |
| throttle_diff | TX vs RX difference | ≤5 |
| steering_diff | TX vs RX difference | ≤5 |
| avg_rssi | Signal strength | >-100 dBm |
| matched_pairs | Correlated samples | ≥10 |

## Output Format

### Console Output - Interactive Test

```
============================================================
Interactive Test: BREmote TX on COM3
============================================================

🎯 Center Throttle
   Move throttle to CENTER position (neutral) and press Enter...
   Result: PASS - Throttle at center: 127

🎯 Full Throttle Forward
   Move throttle to FULL FORWARD and press Enter...
   Result: PASS - Throttle at max: 255

🎯 Full Brake
   Move throttle to FULL BRAKE and press Enter...
   Result: PASS - Throttle at brake: 0
```

### Console Output - Radio Link Test

```
============================================================
PHASE 1: Individual Device Tests
============================================================
...

============================================================
PHASE 2: Radio Link Integration Test
============================================================

🔗 Starting Radio Link Test (10.0s)...
   TX: COM3
   RX: COM4

📊 Radio Link Results:
  Samples: TX=105, RX=103, Matched=102
  Packet Loss: 2.9%
  Avg Throttle Diff: 0.50
  Avg Steering Diff: 0.30
  RSSI: -72 dBm (min: -75)
  SNR: 8.5 dB
  Result: PASS
  Details: Radio link working correctly
```

### JSON Report Format

```json
{
  "COM3": {
    "device_type": "tx",
    "port": "COM3",
    "timestamp": "2026-02-26T10:30:00",
    "tests": {
      "thr_center": {
        "result": "PASS",
        "details": "Throttle at center: 127"
      },
      "thr_max": {
        "result": "PASS", 
        "details": "Throttle at max: 255"
      }
    },
    "overall_result": "PASS"
  }
}
```

## Troubleshooting

### Device Not Detected

- Ensure the BREmote is powered on and USB is connected
- Check Windows Device Manager for the COM port
- Try different USB cables (some cables are power-only)
- Install CH340 or CP2102 drivers if needed

### Permission Denied

- Close any other programs using the COM port (Arduino IDE, PlatformIO, serial monitor)
- Run as Administrator if needed

### Tests Failing

- Verify the BREmote firmware is flashed correctly
- Check that debug output is enabled (`serialOff = false`)
- Ensure the device responds to `?conf` command

### Radio Link Test Failing

- Ensure TX and RX are paired/bound
- Check antennas are connected
- Verify TX and RX are on the same frequency (868MHz or 915MHz)
- Reduce distance between TX and RX
- Check for interference sources

## Firmware Requirements

For full functionality, the BREmote firmware should support these serial commands:

**TX Commands:**
- `?conf` - Print configuration
- `?printInputs` - Show throttle/toggle values
- `?printRSSI` - Show signal strength
- `?printPackets` - Show packet counters
- `quit` - Stop continuous output

**RX Commands:**
- `?conf` - Print configuration
- `?vesc` - VESC status
- `?pwm` - PWM status
- `?packets` - Radio statistics
- `?printReceived` - Show received values (for link test)

## Extending the Tests

To add custom interactive tests:

```python
def _interactive_custom_test(self, device: BREmoteDevice, gui_root=None) -> TestReport:
    tests = {}
    
    # Add your test
    tests["my_test"] = self._prompt_and_verify(
        "My Custom Test",
        "Instructions for user...",
        device,
        self._verify_my_test,
        gui_root
    )
    
    # ... create and return TestReport

def _verify_my_test(self, device: BREmoteDevice) -> Dict:
    response = device.send_command("?mycommand")
    if "expected" in response:
        return {"result": TestResult.PASS.value, "details": "Success"}
    return {"result": TestResult.FAIL.value, "details": "Failed"}
```

## Requirements

- Python 3.7+
- Windows 10/11
- USB-Serial drivers (CH340, CP2102, FTDI, etc.)
- BREmote V2 hardware with debug output enabled

## License

GPL 3.0 (same as BREmote project)

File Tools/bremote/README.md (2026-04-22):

# BREmote Test Suite

Hardware test application for BREmote V2 TX and RX units.

## Installation

```bash
pip install pyserial
```

## Usage

### Command Line

```bash
# Scan for devices
python -m bremote --scan

# Run all tests (auto-detect devices)
python -m bremote

# Test specific port
python -m bremote --port COM3

# Run specific test type
python -m bremote --test all|radio|display|hall|analog|vesc|pwm

# WiFi/Web config tests only
python -m bremote --wifi

# Radio link integration test (requires TX+RX)
python -m bremote --link --duration 15

# Interactive tests (with user prompts)
python -m bremote --interactive

# Interactive tests (with user prompts)
python -m bremote --interactive

# Save report to file
python -m bremote --report results.json
```

### Python API

```python
from bremote import BREmoteTester, BREmoteDevice

# Create tester
tester = BREmoteTester()

# Scan for devices
tester.scan_ports()

# Run all tests
tester.run_all_tests()

# Run specific test types
tester.run_wifi_tests()
tester.run_integration_test(duration=10.0)

# Cleanup
tester.cleanup()
```

---

## Tests

### TX Tests (`tx_tests.py`)

| Test | Command | Description |
|---|---|---|
| `radio` | `?state`, `?printPackets` | Verify radio subsystem active |
| `display` | `?state` | Verify LED matrix display working |
| `hall` | `?printInputs` | Test throttle/steering sensors |
| `analog` | `?state` | Verify ADC/battery monitoring |
| `rssi` | `?printRSSI` | Check radio signal strength |

### RX Tests (`rx_tests.py`)

| Test | Command | Description |
|---|---|---|
| `radio` | `?printrssi` | Verify radio link status |
| `vesc` | `?printbat` | Test VESC/battery interface |
| `pwm` | `?printpwm` | Verify PWM output signals |

### WiFi Tests (`wifi_tests.py`)

| Test | Device | Commands | Description |
|---|---|---|---|
| `wifi_state` | TX | `?wifi`, `?wifistate` | Query WiFi status |
| `wifi_debug` | TX | `?wifidbg` | Test debug mode get/set |
| `wifi_timeout` | TX | `?wifips` | Test AP startup timeout |
| `wifi_version` | TX | `?wifiver` | Check web UI version |
| `wifi_error` | TX | `?wifierr` | Query last error |
| `wifi_onoff` | TX | `?wifi on/off` | Test enable/disable |
| `wifi_ui_update` | TX | `?wifiupd` | Force UI update to SPIFFS |

### Config Tests (`config_tests.py`)

| Test | Device | Commands | Description |
|---|---|---|---|
| `config_keys` | TX/RX | `?keys` | List all config keys |
| `config_get_set` | TX/RX | `?get`, `?set` | Test get/set values |
| `spiffs` | TX/RX | `?conf` | Verify SPIFFS storage |

### Link Test (`link_test.py`)

| Test | Description |
|---|---|
| `RadioLinkMonitor` | Correlates TX throttle/steering with RX received values over radio link. Measures packet loss, latency, RSSI, SNR. |

---

## Exit Charging Mode

The test suite automatically sends `?exitchg` to TX on startup to exit charge screen mode.

---

## Requirements

- Python 3.7+
- pyserial

---

## File Structure

```
Tools/bremote/
├── __init__.py           # Package exports
├── models.py             # Data classes
├── device.py            # Serial communication
├── runner.py            # Test orchestrator
└── tests/
    ├── __init__.py
    ├── tx_tests.py      # TX tests
    ├── rx_tests.py      # RX tests
    ├── wifi_tests.py    # WiFi tests
    ├── config_tests.py  # Config tests
    └── link_test.py    # Radio link correlation
```

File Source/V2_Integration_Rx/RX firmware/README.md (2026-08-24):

# BREmote RX — prebuilt firmware

Flash these directly with **esptool** — no Arduino IDE, no toolchain, no compiling.

Board: **HT-CT62 (ESP32-C3)** · **custom partition table** (`partitions.csv` in this sketch
folder) · app offset **`0x10000`**

## Which one do I want?

| File | SW | What it is |
|---|---|---|
| `BREmote-RX-SW35R3-compasscal-fix.bin` | **35** | **Start here.** Everything in `audit-fixes`, plus a fix for **`?compasscal` rejecting perfectly good calibration runs.** It aborted with *"only 1 deg of rotation seen"* no matter how well the circles were walked — on any buggy whose hard-iron offset is larger than its field strength, which is common rather than exotic. The check measured the turn from the wrong reference point: it watched the angle from the origin instead of from the centre of the readings, and when the offset is the bigger number that angle rocks back and forth over a small arc and returns to where it started. Two full circles measured as zero. Reported by a beta tester whose raw numbers proved it exactly. Rotation is now accumulated about the centre of the swept field, in a second pass once that centre is known. **No threshold changed** — they were being fed a number that did not measure what it claimed. Same `SW_VERSION` **35** and same **192-byte** `confStruct` as the build below, so **moving between the two does NOT touch your settings.** |
| `BREmote-RX-SW35R2-audit-fixes.bin` | **35** | The previous SW35 build, kept for rollback. ⚠️ **`?compasscal` cannot complete on some hardware** — see the build above. Everything in `compass-orientation`, plus the fixes from a full pre-publication audit. Most visibly: **the RX's own WiFi config page was dead** in the build below — it rendered no fields and no button worked. Also: blocking bench commands (`?compasscal`, `?magtest`, `?download`, and 19 more) now refuse to run, and abort if started, while RTM or Follow-Me is engaged; `gps_dyn_model` is finally honoured on M9/M10 modules; a GPS left UBX-only by a drone flight controller is now detected and repaired; and a sloppy compass calibration can no longer silently overwrite a good one. Same `SW_VERSION` **35** and same **192-byte** `confStruct` as the build below, so **moving between the two does NOT touch your settings.** |
| `BREmote-RX-SW35-compass-orientation.bin` | **35** | The previous SW35 build, kept for rollback. ⚠️ **Its WiFi config page does not work** — use the build above. Everything below, **plus compass mounting orientation** — `?compasscal` now measures it for you. ⚠️ **Coming from SW34, this resets your config once.** See below. |
| `BREmote-RX-SW34-dyn-model.bin` | 34 | The last SW34 build. Everything in `dual-compass` **plus a selectable GPS dynamic model** — set `gps_dyn_model 4` if you ride above ~500 m altitude. See below. |
| `BREmote-RX-SW34-dual-compass.bin` | 34 | **Field-verified by a beta tester** on an HGLRC M100-5883 (2026-08-16). Everything in `gps-verified` **plus automatic compass detection** — drives the **QMC5883L** (BN-880) *or* the **QMC5883P** (HGLRC M100-5883) from one image, chosen at boot by I²C address. See below. |
| `BREmote-RX-SW34-gps-verified.bin` | 34 | The previous build, **kept deliberately** — the field-proven one. QMC5883L only. ACK-verified GPS config with automatic `CFG-VALSET` fallback, so it works with a BN-880 *and* with an M10. Adds `?gpsbaud`, `?gpssetup`. |
| `BREmote-RX-SW34-pre-gpsbaud.bin` | 34 | The build immediately **before** the baud work. Use this to isolate whether a problem is GPS-related. |
| `BREmote-RX-SW32-rtm-working.bin` | 32 | Known-good historical build from 2026-06-05. RTM working; Follow-Me not yet matured. Fallback if something newer misbehaves. |

### BIND LED — reading the calibration result (updated 2026-08-18)

The LED reports which of three outcomes actually happened. **The patterns differ in how long the
lamp stays LIT, not only in how many times it flashes** — so you can tell them apart at a glance
without counting, including when you look over halfway through and miss the start.

| Outcome | Pattern | What you see | Length |
|---|---|---|---|
| **FULL** | 2 flashes, short | *blip-blip* | 0.4 s |
| **PARTIAL** | 3 flashes, **long and slow** | *PULSE… PULSE… PULSE* — the lamp is visibly on | 2.1 s |
| **REJECTED** | 10 flashes, fast | *buzzzz* | 1.0 s |

Each pattern is preceded by a short dark gap so you can tell where it begins.

**PARTIAL is the one that matters.** It means the iron calibration was saved but **the mounting
angle was NOT re-measured**, so a module that has just been re-mounted still has the old angle
stored and every heading is out by the difference. Walk it again: two full clockwise circles,
starting and finishing with the nose on north.

> Before 2026-08-18 all three patterns ran at one speed — 50 ms on, 50 ms off. FULL and PARTIAL
> were therefore 200 ms and 300 ms of 10 Hz flicker, a 100 ms difference at a rate people cannot
> count. If you have an earlier copy of `BREmote-RX-SW35R3-compasscal-fix.bin`, re-download it:
> the filename is unchanged, the flash size is 1,342,192 B.

### What `dual-compass` adds (2026-08-15)

The RX now **detects which magnetometer is fitted at boot** and drives it correctly. One image,
either module:

| I²C address | Part | Found on |
|---|---|---|
| `0x0D` | **QMC5883L** | Beitian BN-880, HGLRC M100 Pro |
| `0x2C` | **QMC5883P** | HGLRC M100-5883 |
| `0x1E` | HMC5883L | very old BN-880 stock — **reported, not supported** |

`?i2c` names whichever it finds, and the boot log says which part it is driving.

**Why this needed a real driver and not just a new address.** The two parts are different silicon,
not a revision. Most importantly their data block starts at a **different register** — `0x00` on the
L, `0x01` on the P. Reading a P with the L's driver returns `CHIPID, XL, XH, YL, YH, ZL`: every axis
shifted one byte. It does not error. It returns a smooth, plausible, completely wrong heading — which
on a Follow-Me buggy is a safety problem, not a cosmetic one. The read path branches on the detected
part for exactly that reason.

They also differ in sensitivity at 8 G (3000 vs 3750 LSB/G) and in axis frame.

> ⚠️ **Re-run `?compasscal` after changing GPS/compass module.** Stored `mag_offset_*` values are raw
> counts and do not survive a part change. Heading is `atan2(y, x)` so a uniform scale error cancels —
> the offsets do not. The firmware prints this reminder at boot.

> ⚠️ **Not yet bench-tested on a QMC5883P by the maintainer.** Written from the QST datasheet and
> cross-checked against iNav and Betaflight, and it compiles clean — but no M100-5883 has been in my
> hands. The QMC5883L path is byte-for-byte unchanged from `gps-verified`, so **BN-880 builds are
> unaffected**. If you fit an M100-5883, please point the buggy north / east / south / west after
> calibrating and confirm the heading tracks, then report back.
>
> **Both builds are `SW_VERSION` 34, so moving between them does NOT touch your settings** — flash
> either way freely, no re-pairing, no re-calibration.

### What `dyn-model` adds (2026-08-16)

**`gps_dyn_model` — the u-blox navigation filter's platform model, now a setting.**

| Value | Model | Use it when |
|---|---|---|
| **0** | default → Sea | **Leave it here.** What every board already does. |
| **4** | Automotive | **You ride above ~500 m altitude.** Sea has a 500 m ceiling and fixes degrade above it. |
| **5** | Sea (explicit) | Same as 0, stated outright. |

```
?set gps_dyn_model 4
?save
```
Reboot. The boot log then reads `dynModel=Automotive` instead of `dynModel=Sea`.

**Why Sea remains the default.** Below 500 m it is the better model: it constrains the filter to
~25 m/s and pins altitude near the surface, which removes a degree of freedom and sharpens
course-over-ground — and COG is what Follow-Me actually steers on. Switching everyone to Automotive
would cost every sea-level rider that sharpening to fix a problem they do not have.

**Why Portable is not offered.** u-blox's dynModel 0 permits 310 m/s. It is what produced the bogus
254 km/h / 4800 m *high-confidence* fixes that started this whole line of work. Anything that is not
an explicit `4` resolves to Sea, so a corrupt or out-of-range value fails toward the conservative
model — never toward Portable.

> **No config wipe.** This reuses a reserved `uint16_t` slot renamed in place, so
> `sizeof(confStruct)` stays 184 and `SW_VERSION` stays 34. Every existing board reads `0` there,
> which means Sea — exactly what it did before. Nothing to re-pair, nothing to re-calibrate.

### What SW35 adds — compass mounting orientation (2026-08-16)

**`?compasscal` now starts and ends pointing north, and measures three things in one run:**

1. Hard/soft-iron calibration — as before
2. **Mounting handedness** — from which way the heading ran while you turned clockwise
3. **Mounting rotation** — from the first sample, taken while pointing north

**Prerequisite — mount the module square to the buggy.** Its own forward axis lined up with the nose,
or turned exactly 90°, 180° or 270° from it. Not diagonal. The rotation is stored only as one of those
four values, so a module at, say, 30° is stored as 0° and keeps 30° of heading error that **no**
calibration can remove. Get this right before you calibrate, not after.

**The new procedure:**

```
Point the nose of the buggy at NORTH
Run ?compasscal  (or short-press BIND)
Rotate SLOWLY CLOCKWISE, two full circles
Finish with the nose back on NORTH
```

Clockwise matters — the turn direction is how handedness is detected. Ending on north is how the
result is checked.

**Why this exists.** Heading is `atan2(y, x)` on the sensor's own axes, so mounting the module
rotated made every heading wrong by that angle, and the old calibration was mathematically blind to
it — a rotation leaves the calibration circle centred and round, so nothing looked wrong. Mount it
square, in whichever of the four orientations fits; tell the firmware once.

**Check the run against itself.** A completed run prints `Mounting orientation: measured NNN deg,
stored NNN deg.` If those two differ by more than a few degrees the module is not square, and the
difference is the heading error left behind — re-mount and re-run.

**Tolerances are deliberately forgiving** — a rejected calibration costs you a re-run on your feet:

| Check | Limit |
|---|---|
| Total rotation seen | ≥ 400° (want ~720°) |
| Finish vs start | within ±40° |
| Rotation stored | snapped to 0 / 90 / 180 / 270 |

If a run is too sloppy to trust, **the iron calibration is still saved and the previous orientation
is kept** — it never stores a guess. That is the failure ArduPilot warns about, where a calibration
*"appears to succeed while leaving the compass in a very bad state."*

**Mirrored modules** (antenna-down, or a chip whose axes are handed the other way) are stored as a
**negative `mag_scale_y`** — negating that axis *is* the mirror fix, and the field already existed.

> ⚠️ **SW35 resets your configuration once.** `confStruct` grew from 184 to 192 bytes, so the
> firmware rewrites config to defaults on first boot. **Back up first with `?conf`**, restore after
> with `?setconf <blob>` + `?applyconf`. You will need to re-pair and re-run `?compasscal` —
> which you want to do anyway, since that is what sets the new orientation.

### Which heading mode should I run? (`rtm_use_compass`)

RTM needs to know which way the buggy is pointing. There are two real choices:

| Mode | Set | What it does | Run it when |
|---|---|---|---|
| **Hybrid** | `1` *(default)* | GPS course while moving; compass when too slow for course to be reliable | Your compass is calibrated and its mounting orientation is set |
| **GPS COG only** | `0` | Steers only above ~3 km/h. Below that it holds straight instead of using the compass | You suspect the compass, or you want to prove whether it is the problem |
| Compass only | `2` | **Bench diagnostic. Never on water.** | Never |

```
?set rtm_use_compass 0
?save
```

> ⚠️ **You must set BOTH.** `rtm_compass_required` does not check for a compass despite its name —
> it requires a valid *heading of any kind* before RTM will arm. With the compass disabled there is
> no heading while the buggy sits still, and RTM is armed from a standstill, so arming fails every
> time with `STOP: No valid heading source`. It reads like COG-only mode is broken; it is the gate.
>
> **The firmware now fixes this for you.** Set `rtm_use_compass 0` and it clears `rtm_compass_required`
> automatically, printing a note on serial explaining what changed and why. You cannot end up with the
> broken combination — not by hand, and not by restoring an old config backup that contains it.

**What COG-only costs you:** steering at low speed and on the final approach. As RTM decelerates it
stops steering and coasts in straight — less precise. **What it buys you:** the compass cannot
contribute an error, because it is never read.

**Worth doing as an A/B.** Run the same spot twice, one mode each, and see which behaves better on
your build. If COG-only is clean and Hybrid is not, the compass is your problem.

### Also in SW35 — RTM heading trust

Two fixes beyond the compass orientation work:

- **RTM will no longer steer on a compass that has been caught disagreeing with GPS.** That check
  existed but was only ever applied to Follow-Me — Return-to-Me never read it. RTM now holds
  straight instead, which at close range is the safe outcome.
- **A GPS course that was valid moments ago is now held for 3 seconds** before falling back to the
  compass. RTM drives at 4.0 km/h while GPS course is abandoned below 3 km/h, and that 1 km/h margin
  is inside the speed signal's own noise — so the heading source was flipping on noise alone, and
  every flip handed steering to a compass that is badly wrong under motor load.

## Flash it

```bash
esptool --chip esp32c3 --port COM<N> write-flash 0x10000 BREmote-RX-SW35R2-audit-fixes.bin
```

> ⚠️ **Back up first if you are coming from SW34 or SW32** — that flash resets your config and
> compass calibration once. `?conf`, then `?setconf <blob>` + `?applyconf` afterwards, re-pair,
> re-run `?compasscal`. Same applies in reverse: substituting an **SW34** filename into that
> command while you are on SW35 is a rollback and wipes the same things. Moving between two
> **SW35** builds wipes nothing. Full table under *Read this before flashing an RX*, below.

**Identify the board by MAC, not by COM number.** The TX and RX are the same chip and COM
numbers move between reboots:

```bash
esptool --chip esp32c3 --port COM<N> read-mac
```

## 🚨 Read this before flashing an RX

**The RX uses its own `partitions.csv` — 2.0 MB app + 1.875 MB SPIFFS.** Never build or flash it
with `PartitionScheme=huge_app`. That overrides the custom table, **halves SPIFFS, moves it, and
wipes your config, compass calibration and all on-board logs.**

Verify the table matches before writing — if the digest matches, your data survives:

```bash
esptool --chip esp32c3 --port COM<N> verify-flash 0x8000 <build>.partitions.bin
```

**Back up first.** `?conf` prints a Base64 blob; `?setconf <blob>` then `?applyconf` restores it.
On the RX the expensive fields are the **compass calibration** (`mag_offset_*`, `mag_scale_*`) —
losing those means re-running `?compasscal` physically — plus pairing.

These are **app-only** images (`0x10000`), so they do not touch the partition table or SPIFFS.
The flash itself never erases your settings. **The firmware does** — it compares the stored
`SW_VERSION` against its own on boot and rewrites the config to defaults when they differ. So
what costs you a calibration is **the SW number in the filename, not the act of flashing**:

| Moving between | Config, pairing | Compass calibration |
|---|---|---|
| **SW35 ↔ SW35** — any two SW35 builds | kept | kept |
| **SW34 ↔ SW34** — any two of the four SW34 builds | kept | kept |
| **SW34 → SW35** — the recommended upgrade | **reset once** | **reset once** |
| **SW35 → SW34** — rollback | **reset** | **reset** |
| **anything ↔ SW32** | **reset** | **reset** |

There are **four** SW34 builds — `dual-compass`, `dyn-model`, `gps-verified` and `pre-gpsbaud` —
and they are interchangeable with each other; move between them freely. SW35 builds are likewise
interchangeable with each other: the rebuild listed at the top of this page keeps `SW_VERSION` 35
and `confStruct` at 192 bytes, so **replacing one SW35 image with another costs you nothing** —
no re-pairing, no re-calibration. It is only the **34/35 line** that has a price.

> ⚠️ **Crossing the 34/35 line is expensive in both directions, and `SW32` doubly so.**
> `confStruct` is 184 bytes on SW34 and 192 on SW35, so there is no version of that crossing that
> can be made painless. It **wipes the compass calibration** — which you can only restore by
> physically re-running `?compasscal`, walking the buggy through two full circles — **plus pairing
> and every setting.** Rolling back to `SW32-rtm-working` costs the same, and coming forward again
> wipes it a second time.
>
> **Back it up before you roll back** (`?conf`), and only roll back if you actually need to.
>
> *(This paragraph previously said the current build was **34** and that "all three SW34 builds are
> interchangeable". The current build is **35**, there are **four** SW34 builds, and every one of
> them is now a wipe-inducing rollback. Being wrong here costs a calibration you redo on your feet.)*

## After flashing

The RX has **no display**, but it does have two LEDs on the AW9523 expander — **BIND** and **AUX** —
and on the calibration path the BIND LED is the *only* channel there is: nobody is watching a serial
terminal while walking a buggy round a car park. After a `?compasscal` run (serial command or a short
BIND press) it tells you which outcome you actually got:

| BIND LED | Verdict |
|---|---|
| **5 flashes** | Calibration starting — begin rotating |
| **2 flashes** | **Full success** — iron calibration, handedness and mounting orientation all updated |
| **3 flashes** | **PARTIAL** — iron calibration saved, **mounting orientation NOT re-measured.** Re-run with two full clockwise circles, especially if you have just re-mounted the module |
| **10 flashes** | **Failed — nothing saved.** No compass detected, too few samples, or the buggy was never really turned |
| *nothing* | The run was aborted (RTM/FM engaged mid-calibration), or it was refused before it started |

The 3-flash case is the one worth reading twice: a re-mounted module whose orientation was not
re-measured leaves every heading out by the mounting angle while looking, to the rider, exactly like
a good run. That is why it now has its own pattern instead of blinking 2 like everything else.

For everything else, serial is the diagnostic surface. Watch the boot log:

```
GPS: heard the module at 115200 baud
GPS config [legacy CFG (u-blox 6/7/8)]: dynModel=Sea OK | GSV OK | GLL OK | VTG OK
```

Then confirm independently:

```
?gpscfg      →  expect  dynModel : 5 (Sea)
```

⚠️ `?gpsbaud` and `?gpssetup` block the main loop for several seconds — RTM/FM and VESC polling
stop while they run. **Bench only. Never with the buggy powered for a run.**

If anything looks wrong, see [`docs/hardware/gps-troubleshooting.md`](../../../docs/hardware/gps-troubleshooting.md).

> Full-flash `.merged.bin` images are deliberately **not** published here. They are 4 MB each and
> overwrite the whole chip including SPIFFS — which on the RX means your compass calibration.

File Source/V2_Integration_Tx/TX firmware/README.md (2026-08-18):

# BREmote TX — prebuilt firmware

Flash these directly with **esptool** — no Arduino IDE, no toolchain, no compiling.

Board: **HT-CT62 (ESP32-C3)** · partition scheme `huge_app` · app offset **`0x10000`**

## Which one do I want?

| File | SW | What it is |
|---|---|---|
| `BREmote-TX-SW27R3-gps-dyn-model.bin` | 27 | **Start here.** Everything in `SW27R2-haptics` **plus a selectable GPS dynamic model for the remote's own GPS.** The TX was hard-coded to the Sea model, which has a **500 m altitude ceiling** — above that, fixes degrade. Now settable, exactly as on the RX: `?set gps_dyn_model 4` then `?save`. Same `SW_VERSION` **27** and same **136-byte** `confStruct`, so **this flash does NOT reset your config** — throttle calibration and pairing are kept. **The reduced vibrations are now the standard behaviour**, not an experiment: a deliberate disarm and a mode cycle are silent, while every uncommanded stop still buzzes. |
| `BREmote-TX-SW27R2-haptics.bin` | 27 | The previous build, kept for rollback. Same reduced vibrations as above, without `gps_dyn_model`. |
| `BREmote-TX-SW27-ubx-checksum.bin` | 27 | Rollback to the **original vibration behaviour** — every stop and mode change buzzes. Everything in `gps-verified` **plus** the UBX checksum fix below. ⚠️ No `gps_dyn_model`, so if you ride above ~500 m you need the top row. |
| ~~`BREmote-TX-SW27-haptics.bin`~~ | 27 | ⚠️ **Withdrawn — do not use.** The vibration cull was applied in the wrong place: it silenced the *uncommanded* stops (RTM max-runtime, GPS stale, throttle-release timeout, and the RX fault-stop) as well as the deliberate ones, so the buggy could stop on its own with no buzz at all. `SW27R2-haptics` above replaces it and restores exactly those. |
| `BREmote-TX-SW27-gps-verified.bin` | 27 | The previous build, **kept deliberately**. Field-proven — this is the one that has actually been ridden. Every GPS config write is ACK-verified, auto-detects u-blox M8 vs M9/M10, never transmits at an unconfirmed baud. Adds `?gpscfg`, `?gpsbaud`, `?gpssetup`. |
| `BREmote-TX-SW26R2-rtm-working.bin` | **26R2** | Known-good historical build from 2026-06-05. RTM working; Follow-Me not yet matured. Fallback if something newer misbehaves. ⚠️ **Different `SW_VERSION` — see below.** |

### What changed in `ubx-checksum` (2026-08-15)

`ubxPoll()` was accepting a GPS config reply as soon as it had the payload, **without ever reading
the two checksum bytes**. Any byte sequence in the stream that looked like a valid UBX header was
believed. That function decides whether your module speaks the legacy u-blox 6/7/8 dialect or the
M9/M10 one, and `?gpssetup` writes in whichever dialect it reports — so a false verdict means the
module is sent commands it cannot parse and **configuration fails silently**.

Not theoretical: the RX had the identical bug and reported a BN-880 (an M8) as "M9/M10" on three
consecutive runs. Fixed on the RX in `1f2ba8c` (2026-08-02); this is the same fix applied to the TX.

**All three SW27 builds — `haptics`, `ubx-checksum` and `gps-verified` — are `SW_VERSION` 27, so
moving between them does NOT touch your settings.** Flash any of them either way freely — no
re-pairing, no re-calibration. Only `SW26R2` is a different version; see below.

> ⚠️ **`ubx-checksum` has not been bench-tested yet.** It compiles clean and the change is confined
> to the GPS config path — nothing in throttle, steering, PWM or failsafe is touched — but no one has
> run it on hardware. `gps-verified` remains the field-proven build. If anything looks off, drop back
> to it; the two are interchangeable.
>
> Verifying it takes a minute: `?gpscfg` should name the correct dialect for your module, and
> `?gpssetup` should complete.

> The RX folder has an intermediate `pre-gpsbaud` build. The TX equivalent was withdrawn
> and is deliberately not published.

### What `haptics` changes (2026-08-17)

A rider holding the remote while concentrating on a wave does not decode vibration patterns — they
feel *a buzz*. Twenty-five buzz events across seven patterns is not a language, it is noise. Six
events are gone:

**Removed — you get no buzz when YOU do it:**
- Disarming RTM by steering or by the magnet toggle, disarming FM the same two ways, or selecting F0.
  You just did it, and the display already shows the stop. This was the most frequent buzz in the
  system.

**Kept — everything that tells you something you did not already know:**
- Arm confirm. You cannot watch the display while riding.
- Weak signal, radio failsafe, water ingress (E7). These must cut through and are never suppressed.
- Magnet "release now" prompts — a blind gesture needs to be told when to let go.
- Arm window expired — the system changing state without you.

**One long buzz means the system stopped without you asking** — RTM hitting its runtime limit, the
TX losing its GPS fix, the throttle-release timeout expiring, or the RX faulting and stopping
Follow-Me. It also fires when an **arm is refused**, which is the same class of information: the
mode you just asked for is not running.

> ⚠️ **The first `haptics` build (`SW27-haptics`, withdrawn) got this backwards.** The cull was
> applied inside the two shared functions that end an engagement — but those serve the automatic
> stops as well as the deliberate ones, so *every* uncommanded stop went silent while the buzz
> survived only on arm refusals. `SW27R2-haptics` classifies each of the ten call sites explicitly
> and restores all five automatic stops.

Two delivery bugs are fixed alongside it. A stop buzz now genuinely preempts: it is raised as a
pending request that is promoted ahead of every other pattern and cuts a multi-pulse pattern short
between pulses, instead of being silently overwritten by whatever was already playing (Pattern 3
runs four seconds — long enough to swallow a stop buzz entirely). And the weak-signal warning no
longer marks itself as "given" when the collision guard stopped it from ever playing, so a signal
drop that coincides with another buzz is still reported.

## Flash it

```bash
esptool --chip esp32c3 --port COM<N> write-flash 0x10000 BREmote-TX-SW27-ubx-checksum.bin
```

**Find your port by MAC, not by COM number** — COM numbers move between reboots, and the TX and
RX are the same chip:

```bash
esptool --chip esp32c3 --port COM<N> read-mac
```

## Before you flash

**Back up your config.** `?conf` prints a Base64 blob; `?setconf <blob>` then `?applyconf`
restores it. Throttle calibration and pairing are the expensive things to lose.

**Check the partition table hasn't moved** — if it matches, your settings survive:

```bash
esptool --chip esp32c3 --port COM<N> verify-flash 0x8000 <build>.partitions.bin
```

These are **app-only** images (`0x10000`). They do not touch the partition table or SPIFFS, so
the flash itself never erases your settings.

> ⚠️ **But rolling back to `SW26R2` DOES reset your config, and that is not the flash's doing.**
> The firmware compares the stored `SW_VERSION` against its own on boot; when they differ it
> rewrites the config to defaults. `SW26R2` is version **26**, the current build is **27**, so
> going backwards **wipes throttle calibration, pairing and every setting**.
>
> **Back up first — `?conf` — and expect to restore with `?setconf <blob>` + `?applyconf` and
> re-pair.** Moving *forward* again from 26R2 to 27 wipes it a second time, for the same reason.
>
> *(This paragraph previously claimed `SW_VERSION` was 27 across all builds and that switching
> between them was safe. It was wrong, and it was wrong in the direction that costs you a
> calibration.)*

## After flashing

The TX sits on the **charge screen** while USB is connected — that is normal, and GPS init has
not run yet. Send **`?exitchg`** to boot through. Then:

```
?gpscfg      →  expect  dynModel : 5 (Sea)
```

If it says anything else, see [`docs/hardware/gps-troubleshooting.md`](../../../docs/hardware/gps-troubleshooting.md).

> Full-flash `.merged.bin` images are deliberately **not** published here. They are 4 MB each and
> overwrite the whole chip including your settings — the wrong tool for updating a working remote.

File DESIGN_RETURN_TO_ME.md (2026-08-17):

# Return-to-Me (RTM) and Follow-Me Override - Design Document
**Project:** BREmote V2.5-Evo  
**Date:** April 21, 2026  
**Status:** Implemented and operational — Beta release as of V2.5-Evo P8/P9. RTM and FM mode selection are live. FM autonomous following (Priority 9) is not yet implemented. Full field test pending.

---

## 1. Purpose and Philosophy

Two new user-activated modes on the TX toggle, both strictly respecting the creator safety philosophy:
- Tow Buggy ONLY moves when user physically holds throttle trigger
- Autonomous systems can only steer and subtract from throttle, never add
- Release throttle = buggy stops immediately, always

### Mode A: Return-to-Me (RTM / "rn")
For when user is sitting on board drifting slowly in water, activate mode to have the buggy come toward their GPS location. User must actively hold throttle to drive it home. Buggy performs automatic steering only, capped and ramped throttle. Hard stop at configured safe distance.

### Mode B: Follow-Me Mode Override (FM)
In-session override of RX's follow-me behavior without modifying RX SPIFFS. Cycles through F0=Off, F1=Right, F2=Behind, F3=Left. Resets to RX web-configured default on reboot.

---

## 2. User Interaction Design

### 2a. RTM Activation Sequence

Step 1: User performs gesture: RIGHT tap, then LEFT hold for `rtm_hold_duration_s` seconds (default 5s)  
Step 2: Dot display shows "rn" blink — mode armed, arm window starts (`rtm_arm_window_s`, configurable)  
Step 3: User squeezes throttle above 10% — motor engages immediately with ramp cap  
*(Note: this paragraph previously said double-squeeze was deprecated in P8 and defaulted to 0. Both were wrong. `runDoubleSqueezeArm()` handles the double-squeeze ceremony and is live; `rtm_double_squeeze_en` **defaults to 1**, so a factory-reset TX requires the deliberate double squeeze. Set it to 0 for a single squeeze held ~500 ms. The shipped value was 0 until 2026-08-17 while every comment and table said 1 — an arming gesture that was easier to trigger by accident than intended. "Arm" and "rdy" display codes no longer appear in firmware.)*  
Step 4: Throttle ramps from `rtm_throttle_start_pct` (default 30%) to `rtm_throttle_max_pct` (default 70%) over `rtm_ramp_duration_s` seconds (default 5s)  
Step 5: Release throttle at any time → buggy stops immediately (normal failsafe)  
Step 6: If throttle released >10s during active mode → RTM disengages, user must re-activate from Step 1  
Step 7: If user re-grabs throttle within 10s window → ramp restarts from `rtm_throttle_start_pct` (no sudden jumps)  
Step 8: Hard stop when distance to TX < `rtm_stop_distance_m` (default 10m, range 3-20m) → throttle forced to 0 regardless of user input

### 2b. Follow-Me Mode Override Sequence

Step 1: User holds RIGHT toggle at full extent for `fm_hold_duration_s` seconds (default 5s, configurable 4-10s)  
Step 2: Dot shows full-screen confirmation: "F0", "F1", "F2", or "F3" for the selected mode  
Step 3: Each additional right-hold advances one step through the cycle  
Step 4: User releases toggle for 2s without further right-holds → selection locked  
Step 5: TX sends mode change meta-packet 3x with 100ms gap for reliability  
Step 6: RX applies override to runtime RAM variable only (does not write to SPIFFS)  
Step 7: On RX reboot, mode returns to web-configured SPIFFS default

### 2c. Dot Display States

| State | Display | Duration |
|---|---|---|
| RTM armed, waiting for throttle | `rn` blink | Until throttle or arm window timeout |
| RTM armed + throttle squeezed | `rn` blink + unlock animation | 2s confirm |
| RTM active (motor running) | RTM info display (distance or speed) | While active |
| RTM disengaged or hard stop | `St` (large-font 2s) | 2s then normal telemetry |
| FM mode selected | `F0` / `F1` / `F2` / `F3` full-screen flash | 2s confirmation |
| *(Deprecated)* double-squeeze first squeeze | ~~`Arm`~~ | Removed in P8 |
| *(Deprecated)* double-squeeze ready | ~~`rdy`~~ | Removed in P8 |
| *(Deprecated)* FM cycling abbreviations | ~~`0ff` / `bEh` / `n-R` / `n-L`~~ | Removed in P8 |

---

## 3. Safety Gates

### 3a. Phase A — RX Standalone GPS Validation (always-on, no RTM dependency)

Runs on every RX GPS reading regardless of operating mode.

1. HDOP < `gps_max_hdop` (default 2.0)
2. Implied acceleration between consecutive readings < `gps_max_accel_g` G (default 3.0)
3. Position change since last reading implies speed < `gps_max_teleport_kmh` (default 80 km/h — 2× craft max speed)

After `gps_suspect_threshold` (default 3) consecutive failures → RX GPS marked as **rejected**.  
Rejected GPS blocks RTM arming and all RTM distance calculations.

### 3b. Phase B — TX/RX Handshake Cross-Validation (on connect + every 30s)

Requires 0xF3 meta-packet infrastructure (Priority 4). TX sends its GPS coordinates to RX via 0xF3.

4. TX↔RX computed distance is plausible: < `gps_max_pair_dist_m` (default 500 m)
5. TX GPS speed and RX GPS speed are consistent: difference < `gps_max_speed_diff_kmh` (default 50 km/h)

Failure → RTM arming blocked until next successful handshake. Spoofing event logged to SPIFFS.

### 3c. Phase C — RTM-Active Convergence Checks (~10Hz, only during active RTM)

6. Distance to TX is **decreasing** (convergence verification — buggy is actually moving toward user)
7. VESC ERPM-implied speed is within `rtm_vesc_speed_diff_kmh` (default 20 km/h) of GPS speed
8. TX GPS data age < `tx_gps_stale_timeout_ms` (TX GPS still fresh)

Any Phase C failure → throttle immediately forced to 0, RTM disengages, display shows `St` for 2s.

### 3d. RTM Motor Safety Gates (every loop cycle, ALL must pass while RTM active)

When RTM is active, ALL of the following must be true or motor immediately cuts to 0:

1. User physically holding throttle >10% (creator philosophy rule — absolute, non-negotiable)
2. Phase A GPS not rejected on RX
3. Phase B handshake passed within last 30 seconds
4. Valid TX GPS fix (age < `rtm_gps_timeout_ms`, default 2000ms)
5. Valid RX GPS fix (age < `rtm_gps_timeout_ms`)
6. Valid compass heading on RX (calibrated + reading within range)
7. LoRa link healthy (last control packet < failsafe_time)
8. Within `rtm_max_runtime_s` (default 120s, range 30-300s) since activation
9. Distance to TX > `rtm_stop_distance_m` (hard stop distance)
10. Throttle not released for > 10s (or RTM disengages)

Any gate failure → throttle forced to 0, `St` for 2s, RTM disengages.

---

## 4. SPIFFS Parameters Needed

### 4a. TX side (new parameters to add)

| Name | Range | Default | Units | Description |
|---|---|---|---|---|
| `rtm_enabled` | 0-1 | 1 | bool | Master enable for RTM feature |
| `rtm_hold_duration_s` | 4-10 | 5 | seconds | LEFT hold duration to arm |
| `rtm_arm_window_s` | 5-30 | 10 | seconds | Window to engage throttle after arming |
| `rtm_double_squeeze_en` | 0-1 | 1 | bool | Require double-squeeze (1) or 500ms filter (0) |
| `rtm_throttle_start_pct` | 10-50 | 30 | % | Initial throttle cap when engaging |
| `rtm_throttle_max_pct` | 30-90 | 70 | % | Maximum throttle cap after ramp |
| `rtm_ramp_duration_s` | 2-15 | 5 | seconds | Time to ramp from start to max |
| `rtm_stop_distance_m` | 3-20 | 10 | meters | Hard stop distance from TX |
| `rtm_max_runtime_s` | 30-300 | 120 | seconds | Maximum continuous RTM runtime |
| `rtm_gps_timeout_ms` | 500-3000 | 2000 | ms | GPS loss timeout before safety stop |
| `fm_hold_duration_s` | 4-10 | 5 | seconds | RIGHT hold duration for FM mode cycle |
| `fm_override_enabled` | 0-1 | 1 | bool | Allow TX to override RX follow-me mode |

### 4b. RX side (new parameters to add)

| Name | Range | Default | Units | Description |
|---|---|---|---|---|
| `rtm_rx_enabled` | 0-1 | 1 | bool | RX-side master enable (safety kill switch) |
| `rtm_rx_override_steering` | 0-1 | 1 | bool | Allow RTM to override steering |
| `rtm_compass_required` | 0-1 | 1 | bool | Require valid compass for RTM (safety) |

### 4c. Rule reminder
All 15 new parameters must ALSO be added to:
- confStruct in respective .h files (TX and RX)
- SPIFFS load/save functions
- Web config UI (WebUiEmbedded.h) for both TX and RX
- ConfigService with validation ranges and defaults
- Inline code comments explaining valid range, units, default

---

## 5. LoRa Protocol Extensions (Layered Extension Approach)

### 5a. Design principle
Existing 6-byte control packet at 10Hz is UNTOUCHED - zero regression risk.  
Meta-packets share the same 6-byte format but use a different type byte in position [3].

### 5b. Existing packet types (DO NOT CHANGE)

| Byte[3] | Type | Payload | Frequency |
|---|---|---|---|
| throttle value | Control | [throttle][steering] | 10Hz |
| 0xAB | Pairing request | ... | Rare |
| 0xBA | Pairing response | ... | Rare |
| 0xAC | Pairing confirm | ... | Rare |

### 5c. Meta-packet types

> ⚠️ **No longer "reserved" — 0xF1–0xF4 are implemented and live.** This section was written
> when they were a proposal for a "V3" that was never built; the current version is V2.5-Evo.
> **`docs/MULTI_TX_DESIGN.md` holds the authoritative byte-3 allocation table**, verified against
> the code. Check it — not this table — before allocating a new meta-packet type.

| Byte[3] | Type | Payload [4][5] | Frequency | Purpose |
|---|---|---|---|---|
| 0xF1 | Mode change - RTM state | [rtm_state][reserved] | On event | TX tells RX "RTM is active/inactive" |
| 0xF2 | Follow-Me override | [fm_mode][reserved] | On event | TX overrides RX follow-me mode |
| 0xF3 | TX GPS coords (future) | NEEDS EXPANDED PACKET | 2Hz | For future follow-me implementation |
| 0xF4 | Telemetry extended (future) | [telem_id][telem_val] | As needed | For future BLE forwarding etc |
| 0xF5 | Config override (future) | [param_id][value] | Rare | For future remote config |
| 0xF6-0xFE | Reserved | - | - | Future expansion |

### 5d. Packet collision avoidance

- Opcodes 0xAB, 0xBA, 0xAC reserved for pairing (DO NOT reuse)
- Opcodes 0xF1-0xFE reserved for meta-packets
- Opcodes 0x00-0xAA available for normal throttle values (throttle byte naturally stays in 0-255 range, but valid throttle never exceeds 0xFE so 0xFF unused)
- Opcodes 0xAD-0xEF available for future expansion if needed

### 5e. CRC and address validation

All meta-packets use existing 3-byte address validation and CRC8 at byte[5]. Same security as control packets.

### 5f. Reliability

Meta-packets sent 3 times with 100ms gap between sends. RX considers mode change applied after first valid meta-packet received (de-duplicates by tracking packet sequence).

---

## 6. State Machine Design

### 6a. TX state machine for RTM

States: IDLE → ARMING → ARMED → ACTIVE → COOLDOWN → IDLE

- IDLE: Normal operation, watching for RIGHT tap + LEFT hold gesture
- ARMING: LEFT held after RIGHT tap, counting toward rtm_hold_duration_s
- ARMED: `rn` blink displayed, arm window active, waiting for throttle squeeze
- ACTIVE: Motor engaged, throttle ramping, safety gates checked every loop
- COOLDOWN: `St` for 2s before returning to IDLE
*(SQUEEZE_WAIT state removed — double-squeeze mode deprecated in P8)*

### 6b. RX state machine for RTM

States: NORMAL → RTM_ACTIVE → NORMAL

Driven by meta-packet 0xF1 from TX. All safety gates evaluated locally on RX every loop.

### 6c. FM state machine

TX side: IDLE → CYCLING → CONFIRMING → IDLE  
RX side: Receives 0xF2 meta-packet, updates runtime variable, no SPIFFS write

---

## 7. Failure Modes and Recovery

| Failure | Detection | Recovery |
|---|---|---|
| TX GPS loss | Age > rtm_gps_timeout_ms | Immediate throttle=0, `St` for 2s, RTM disengages |
| RX GPS loss | Age > rtm_gps_timeout_ms | Same |
| Compass invalid | Calibration check fails | Same |
| LoRa link loss | Last packet > failsafe_time | Standard failsafe (existing) |
| VESC stall | ERPM near 0 with throttle > 30% for 20s | Throttle=0, user alerted |
| Max runtime exceeded | runtime > rtm_max_runtime_s | Throttle=0, RTM disengages |
| User releases throttle | Physical | Buggy stops (normal) |
| User releases > 10s | Timer | RTM disengages, user must re-arm |
| GPS spoofing detected | Acceleration > 3g | Throttle=0, RTM disengages |
| Meta-packet not received by RX | No ACK mechanism | User sees no mode change on next telemetry, can re-try |

---

## 8. Test Plan Before Flashing

### 8a. Bench tests (no motor attached)
- Verify TX state machine transitions via serial monitor logs
- Verify meta-packets sent correctly (read RX serial output)
- Verify safety gate logic by forcing fail conditions
- Verify SPIFFS save/load of all new parameters

### 8b. Motor bench tests (motor unloaded, prop removed)
- Verify ramp behavior 30% → 70% over 5s
- Verify throttle=0 on release
- Verify 500ms filter (if single-squeeze mode)
- Verify double-squeeze sequence (if default mode)
- Verify hard stop triggers correctly with simulated GPS coords

### 8c. Controlled water tests (shallow water, tether to buggy)
- Short range RTM test at low speed
- Intentional GPS denial to verify safety stops
- Verify distance-based hard stop

### 8d. Full field test
- Only after all bench and controlled tests pass
- Helmet + PFD, spotter present
- Start with `rtm_throttle_max_pct` at 70-75% (default 70% — this is the recommended field test starting point; 40% is too conservative for meaningful water testing)
- `rtm_throttle_start_pct` controls the ramp start (default 30%); leave at default for first tests
- `rtm_approach_zone_m` controls the decel ramp start distance (default 15m); buggy smoothly reduces throttle to 0 as it enters this zone before the hard stop
- `rtm_stop_distance_m` (RX) is the hard stop distance (default 3m); confirm via RX web config before field use
- `rtm_disengage_distance_m` (TX) is the TX-side disengage threshold — keep ≥ rtm_stop_distance_m (RX)

**Key SPIFFS parameters for RTM field testing:**
| Param | Board | Default | Notes |
|---|---|---|---|
| `rtm_throttle_max_pct` | TX | 70% | Max throttle during RTM run |
| `rtm_throttle_start_pct` | TX | 30% | Ramp start at engagement |
| `rtm_ramp_duration_s` | TX | 5s | Time from start% to max% |
| `rtm_approach_zone_m` | TX | 15m | Distance where decel ramp begins |
| `rtm_disengage_distance_m` | TX | 10m | TX-side disengage trigger |
| `rtm_stop_distance_m` | RX | 3m | Hard stop distance |
| `rtm_max_runtime_s` | TX | 0 (disabled) | 0=no runtime limit |
| `rtm_arm_window_s` | TX | 10s | Window to squeeze after "rn" arm |

**Key SPIFFS parameters for FM field testing (mode selection only — autonomous FM not yet implemented):**
| Param | Board | Default | Notes |
|---|---|---|---|
| `fm_override_enabled` | TX | 1 | Must be 1 to allow F0-F3 cycling via gesture |
| `fm_warn_distance_m` | TX | 150m | TX-RX distance triggers proximity vibration warning |

*FM autonomous following (GPS-guided heading + throttle gating) is Priority 9 and not yet implemented. FM gesture cycles the mode selection on RX; no autonomous steering occurs.*

---

## 9. Implementation Order

### Phase 1: TX GPS reading (Priority 1 - already in progress)
Complete current TX GPS speed implementation (Files 1-6 of GPS work). This provides foundation for knowing TX location.

### Phase 2: LoRa meta-packet infrastructure
- Define meta-packet types in Common/RadioCommon.h
- Update TX Radio.ino to send meta-packets
- Update RX Radio.ino triggeredReceive to dispatch meta-packets
- Test meta-packet reliability (bench test)

### Phase 3: FM Follow-Me Override (easier, good first mode feature)
- Add fm_ parameters to TX SPIFFS + Web UI
- Implement right-hold state machine on TX
- Implement 0xF2 meta-packet on both sides
- Implement runtime override variable on RX
- Test mode switching end-to-end

### Phase 4: RTM Return-to-Me
- Add all rtm_ parameters to TX and RX SPIFFS + Web UI  
- Implement left-hold state machine on TX
- Implement 0xF1 meta-packet on both sides
- Implement safety gates on RX (all 10 gates)
- Implement throttle ramp and distance-based stop
- Implement compass heading integration
- Bench test extensively
- Field test per Test Plan

### Phase 5: Fix critical bugs (from V2 analysis)
Before field testing RTM, all 7 critical bugs from analysis should be fixed to prevent crashes during autonomous operation.

---

## 10. Open Questions

1. What GPIO on RX will be used for potential future relay/lights? (Future expansion, not Phase 4)
2. Should RTM require a minimum user GPS accuracy (HDOP) before arming? (Proposed: HDOP < 2.0)
3. Should RTM include a user-audible/visible confirmation beep/LED when engaging? (TX has no buzzer currently)
4. What happens if user activates RTM but RX has follow-me mode already active? Priority conflict resolution needed.
5. Should there be a "kill switch" - any button press during RTM that immediately disengages?
6. Should RTM auto-disengage if buggy is upside down/flipped? (Would need IMU not present)

---

## Next Steps

1. User reviews this design document
2. Open Questions are resolved through discussion
3. Complete TX GPS implementation (current Priority 1)
4. Fix 7 critical bugs from V2 analysis
5. Begin Phase 2 (LoRa meta-packet infrastructure)
6. Continue through Phases 3-4

**Do NOT begin implementation until this document is reviewed, open questions resolved, and user explicitly approves each phase.**

---

## 11. Dual GPS Anti-Spoofing Architecture

### 11a. Design Overview

TX (BN-220) and RX (BN880) are two independent GPS units that can be cross-validated. Spoofing one unit is plausible. Spoofing both consistently — at close range, while matching VESC telemetry — is implausible. This architecture layers three phases to exploit that redundancy.

Phase A always runs. Phase B activates when TX is paired. Phase C activates only during RTM. Each phase is independently useful; none requires the previous to be implemented first (though B requires 0xF3 infrastructure from Priority 4).

### 11b. Phase A — RX Standalone (Priority 3, ~20 lines in RX GPS.ino)

Always on. No TX dependency. Catches obvious spoofed signals before they reach any RTM logic.

- **HDOP gate**: signal quality check — weak satellite lock rejected immediately
- **Acceleration gate**: physics check — no real vehicle does > 3G without a crash
- **Teleport gate**: continuity check — GPS position cannot jump faster than `gps_max_teleport_kmh` (default 80 km/h, 2× foil/buggy max speed)

These three checks are independent and can be evaluated in any order. Failure counter resets to 0 on any passing reading.

### 11c. Phase B — TX/RX Handshake Cross-Validation (Priority 4 infrastructure, ~30 lines)

On TX connect and every 30 seconds. TX sends its GPS lat/lon via 0xF3 meta-packet. RX receives it and computes:
- Straight-line distance between TX and RX GPS positions
- Difference between TX and RX GPS-reported speeds

If TX and RX GPS agree on both distance and speed within thresholds, both readings are likely real. If they disagree, at least one GPS is wrong (spoofed or faulty). RTM arming is blocked until agreement is restored.

### 11d. Phase C — RTM-Active Verification (Priority 5, ~15 lines in RX RTM state machine)

Only during active RTM. Adds behavioral checks that only make sense when the buggy is supposed to be moving toward the user.

- **Convergence**: if RTM is steering correctly, distance must decrease. Stagnant or increasing distance indicates steering failure, GPS error, or obstacle — stop.
- **VESC cross-check**: the physical drivetrain reports wheel speed. If GPS says 15 km/h but VESC ERPM implies 2 km/h, one sensor is wrong — stop.
- **TX freshness**: stale TX GPS during active RTM means the steering target is invalid — stop.

### 11e. New RX SPIFFS Parameters (7 total — all must follow Section 10 Web Config UI Rule in project notes)

| Name | Range | Default | Units | Phase | Description |
|---|---|---|---|---|---|
| `gps_max_hdop` | 0.5–5.0 | 2.0 | — | A | Maximum HDOP for a valid GPS reading |
| `gps_max_accel_g` | 1.0–10.0 | 3.0 | G | A | Maximum implied acceleration between readings |
| `gps_max_teleport_kmh` | 50–500 | 80 | km/h | A | Maximum position-implied speed for teleport check (80 km/h = 2× max craft speed) |
| `gps_suspect_threshold` | 1–10 | 3 | count | A | Consecutive failures before GPS rejected |
| `gps_max_pair_dist_m` | 50–2000 | 500 | meters | B | Maximum plausible TX-RX distance at handshake |
| `gps_max_speed_diff_kmh` | 10–200 | 50 | km/h | B | Maximum TX-RX speed difference for handshake |
| `rtm_vesc_speed_diff_kmh` | 5–50 | 20 | km/h | C | Maximum GPS vs VESC speed difference during RTM |

### 11f. Implementation Notes

- All 7 parameters must be added to Section 4c rule reminder (confStruct + SPIFFS + Web UI + ConfigService)
- Phase A can be implemented standalone (Priority 3) without touching any other feature
- Phase B requires Priority 4 (0xF3 meta-packet) to be complete first — do not implement B before P4
- Phase C is implemented as part of the RTM state machine during Priority 5
- TX-side code changes are limited to 0xF3 sending (Priority 4); Phases A, B, C all live on RX

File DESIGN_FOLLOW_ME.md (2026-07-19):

# DESIGN_FOLLOW_ME — FM Autonomous Following (Priority 9)

**Project:** BREmote V2.5-Evo
**Date:** July 18, 2026
**Status:** Approved design — not yet implemented. Prerequisite: heading-feedback triage (see §9 Phase 0.5).
**Baseline:** `feature/collision-backoff` @ `d68ed07`.
**Sibling doc:** `DESIGN_RETURN_TO_ME.md` (RTM — implemented, field-tested). FM reuses RTM's validation phases, safety gates, and steering pipeline.

## 1. Purpose and Safety Philosophy

After the whip, the rider releases the rope and rides the wave; the buggy is unmanned on its last heading. FM makes the buggy trail the rider at a configured offset and distance, steering itself, while the rider keeps eyes on the wave.

Non-negotiable (identical to RTM, overrides everything below):
1. The buggy ONLY moves while the rider physically holds the throttle trigger.
2. Autonomous systems ONLY steer and SUBTRACT throttle — never add.
3. Release throttle = buggy stops immediately, always.
4. Every failure path (GPS, compass, LoRa, geometry) drives motor → 0.

FM = autonomous steering + distance-based throttle limiting, under a human throttle hand.

## 2. Canonical mode mapping (single source of truth)

| Mode | Meaning | Geometry |
|---|---|---|
| 0 | Off | — |
| 1 | **Near-Right** (default) | behind-right diagonal at `near_diag_offset_deg` |
| 2 | **Behind** | directly behind rider's course |
| 3 | **Near-Left** | behind-left diagonal |

This TX-side convention is canonical for ALL surfaces (TX display F0–F3, RX struct, both web UIs, README). RX comments/labels currently disagree and must be aligned as part of implementation. Default = 1 (rider is left-foot-forward; the right side is the visible side).

## 3. What already exists (reuse verbatim — do not reimplement)

- **Mode selection plumbing:** TX gesture → 0xF2 meta-packet ×3 → RX `fm_mode_runtime` (RAM). 30 s keepalive; RTM preemption via silent disarm (0xF2/0).
- **Validation:** Phase A (RX GPS: HDOP/teleport/accel → `gps_rejected`), Phase B (TX↔RX cross-validation on 0xF3, 30 s pass / 2 s fail cadence), Phase C pattern (periodic behavioral checks).
- **Steering pipeline** (`RTMState.ino`): EMA target-position filter (τ per preset), P+D controller `kSteerPresets[5]`, heading-source ladder (GPS COG → compass snapshot → live), confidence-scaled authority, wrap-to-±180° error handling.
- **Throttle patterns:** subtract-only cap chain (`PWM.ino:47, 52–55`), approach-zone linear decel ramp, Align-phase ~5 % cap, Run-phase speed governor, engage ramp machinery.
- **Rider position:** 0xF3 GPS meta at 2 Hz (always on with TX fix) — measured sufficient: 2.0–2.4 m rider displacement per update at typical ride speed, 4.5 m at 20 mph, vs 6 m follow gap.
- **Telemetry slots:** `fm_heading_err` (idx 14) and `fm_status` (idx 15) already reserved in `TelemetryPacket`.

## 4. State machine (RX)

```
FM_IDLE → FM_ARMED → FM_ACTIVE → (FM_ARMED | FM_IDLE)
```

- **FM_IDLE:** `fm_mode_runtime` = 0 or unset. New behavior: implement the documented 0xFF → `usrConf.followme_mode` fallback (currently missing).
- **FM_ARMED:** mode 1–3 selected; all monitoring runs; throttle chain inactive until activation conditions met. Display/telemetry reflect armed state (`fm_status`).
- **FM_ACTIVE:** engaged when ALL activation conditions hold (§5). Steering override on; throttle cap chain on (§7).
- **Demotion:** any §5 condition failing → FM_ARMED with throttle cap 0 (motor stops; mode stays selected; re-engages when conditions restore — with the engage ramp, never a jump).
- **Mutual exclusion with RTM:** unchanged (RTM arming silently disarms FM).

## 5. Activation / hold conditions (ALL required while FM_ACTIVE, checked every loop)

1. Throttle held: `thr_received ≥ 25` (absolute rule; motor is already 0 without it).
2. Phase A pass (RX GPS not rejected).
3. Phase B pass (TX↔RX cross-validation current).
4. TX GPS age < `tx_gps_stale_timeout_ms`.
5. RX GPS age < 6000 ms.
6. Valid heading source (per heading ladder; `rtm_compass_required` honored).
7. LoRa healthy: `millis() − last_packet < failsafe_time`.
8. Rider beyond engage distance: `dist > min_dist_m + followme_smoothing_band_m` to activate; deactivate (cap 0) only when `dist < min_dist_m` (Schmitt hysteresis — no flapping at the band edge).
9. Rider moving: rider speed ≥ `foiler_low_speed_kmh`. Below it (rider down, idle, pumping slowly) → cap 0, hold FM_ARMED. Prevents maneuvering around a swimmer.

Failure of 1–7 → cap 0 immediately (same posture as RTM gates). 8–9 are geometric holds, not faults.

## 6. Target-point computation (the new control code)

Per control tick (10 Hz), all on RX:

1. **Filter:** EMA the raw 0xF3 rider position with the active preset's τ (same code path RTM uses).
2. **Rider course + speed:** derived from successive filtered positions. Valid only while rider speed ≥ ~5 km/h (measured: course noise doubles below ~3 mph). Invalid course → degraded mode: offset direction = bearing(rider → buggy) ("hold station at distance"), no diagonal.
3. **Lag anchor:** a first-order EMA trails a moving target by v·τ (13–18 m at 15–20 mph with τ = 2 s — larger than the follow gap and speed-dependent). Correct it: `anchor = filtered_pos + û_course · min(v_rider · τ_active, 2 · d_follow)`. This makes geometry speed-independent without touching the proven smoothing (deliberately NOT solved by shrinking τ: the filter must keep ignoring carves — measured p95 turn rate 49°/s at ~5 m radius; the buggy follows the low-passed path, never mirrors bottom turns).
4. **Trailing point:** `target = anchor − d_follow · R(offset) · û_course`, where `d_follow = min_dist_m + followme_smoothing_band_m` and offset = 0° (mode 2), −`near_diag_offset_deg` (mode 1, rider's right), +`near_diag_offset_deg` (mode 3). Sign convention MUST be fixed against the code's bearing convention and verified in `Tools/FollowMe Settings Visualizer.html` before water.
5. **Steer:** feed `target` to the existing steering pipeline unchanged. Publish `fm_heading_err` and `fm_status` each rotation.
6. **Side-zone hysteresis:** when the angle between rider course and rider→buggy bearing crosses `zone_angle_enter_deg`/`zone_angle_exit_deg`, blend diagonal ↔ pure-behind (Schmitt pair) so an unstable rider course cannot whip the target point across the wake.

## 7. Throttle cap chain (subtract-only; lowest cap wins)

| # | Cap | Source pattern |
|---|---|---|
| 1 | Hard stop: `dist < min_dist_m` → 0 (re-engage per §5.8 hysteresis) | RTM gate-9 distance check |
| 2 | Approach ramp: linear 255→0 across the smoothing band | `RTMState.ino:569–597` verbatim |
| 3 | Speed governor: toward `min(boogie_vmax_in_followme_kmh, rider_speed + closing margin)` | Run-phase governor |
| 4 | Align phase: heading error > threshold → ~5 % cap | Align-phase pattern |
| 5 | Engage ramp: 0→cap over 3–4 s on every FM_ACTIVE entry | RTM ramp machinery |

FM writes caps only. The human trigger remains the sole throttle source; trigger release stops the buggy through the unchanged base architecture.

## 8. Parameters — zero new confStruct fields for v1

All eight existing FM params acquire their intended meaning (no SW_VERSION bump; owner sets values via web UI):

| Param | v1 role | Owner default |
|---|---|---|
| `followme_mode` | SPIFFS default mode (0xFF fallback) | 1 (Near-Right) |
| `min_dist_m` | hard-stop distance | 4 m |
| `followme_smoothing_band_m` | hysteresis + ramp band (follow point = sum = 6 m) | 2 m |
| `near_diag_offset_deg` | diagonal offset (modes 1/3) | 45° |
| `boogie_vmax_in_followme_kmh` | FM speed ceiling | 25 km/h (~15.5 mph) |
| `foiler_low_speed_kmh` | rider-down gate | 8 km/h (~5 mph) |
| `zone_angle_enter_deg` / `zone_angle_exit_deg` | side-zone Schmitt pair | 35° / 45° |

Field-retunable to 4/10/20 m equivalents without reflash. At the next SW_VERSION bump (whenever one happens for other reasons), bake the proven values into `defaultConf` on both sides — a version bump resets stored config to `defaultConf` (verified against `ConfigService`/`SPIFFSEngine`; web-UI-only tuning does not survive bumps).

Deferred to a future bump (one field, shared with RTM): an RX-side autonomous-runtime cap. Neither RTM nor FM has one today (TX `rtm_max_runtime_s` defaults to 0 = disabled).

## 9. Failure modes and recovery

| Failure | Detection | Response |
|---|---|---|
| TX (rider) GPS loss | age > `tx_gps_stale_timeout_ms` | cap 0, hold FM_ARMED, re-engage via ramp on recovery |
| RX GPS loss | age > 6 s | same |
| Heading source invalid | ladder empty | same |
| LoRa loss | > `failsafe_time` | PWM pulses stop (existing failsafe), independent of FM |
| Rider inside stop radius | dist < `min_dist_m` | cap 0 until beyond band |
| Rider down/slow | speed < `foiler_low_speed_kmh` | cap 0, wait |
| Rider course invalid | speed < ~5 km/h | degrade to hold-station (no diagonal) |
| RTM armed | 0xF2/0 silent disarm | FM off (existing) |
| Trigger released | physical | motor stops (base architecture, untouched) |

**Phase 0.5 prerequisite (blocking):** log analysis of all recorded RTM activity shows GPS COG has never engaged as heading source (0 of 1,946 active samples), the compass shows large swings under motor current (evidence contaminated by uncalibrated logs — measure with `?magtest` after the telemetry fix), and steering actuation was intermittent despite valid error. FM ships on this same heading ladder. Before FM implementation: fix the RX GPS feed to the controller, characterize/compensate compass-under-load, close the actuation gap, guard against engagement with no fix, clamp `d_error` across snapshot refreshes. This also resolves the RTM "drives in circles" defect.

## 10. Test plan

1. **Bench, motor off:** mode plumbing end-to-end; simulated coordinates through the target-point math; sign/offset verification against the Settings Visualizer; hysteresis boundaries; every §5 condition force-failed → cap 0.
2. **Bench, wheels up:** cap chain order; engage ramp; align-phase cap; compass-under-load table (from Phase 0.5).
3. **Controlled water, tethered:** mode 2 (Behind) only, walking-pace rider, hard-stop verification, GPS-denial stop.
4. **Field, incremental:** mode 2 first at 6 m; then mode 1 (Near-Right); throttle hand ready to cut throughout; logging enabled (aux button) every run.

## 11. Implementation order

1. Phase 0.5 heading-feedback triage (blocking).
2. RX: FM state machine + activation conditions (§4–5).
3. RX: target-point computation (§6) feeding the existing steering pipeline.
4. RX: throttle cap chain (§7) from existing patterns.
5. Both web UIs + RX comments: canonical mapping + param descriptions (§2, §8); README table.
6. Telemetry: populate idx 14/15; TX display FM-active state.
7. Safety audit (motor-safety verdict first), then §10 gates in order.

No TX control-path changes. No LoRa protocol changes. No new packets, no rate changes (2 Hz 0xF3 measured sufficient).

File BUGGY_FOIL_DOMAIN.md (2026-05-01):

# Tow Buggy + Foil Surfing — Domain Context for BREmote V2.5-Evo

## What the Buggy Is
The tow buggy ("buggy" or "boogie") is a motorized watercraft — roughly the size
and role of a small powered surfboard or mini jet ski. It does not carry a rider.
It tows the foil surfer behind. The user holds the remote control (TX) at all
times while in the water. The buggy is the motor; the foiler is the payload.

## Steering Types
Three distinct steering modes exist in this system. Understanding the difference
is critical for safe code changes.

**Tow steering (passive):** During the tow phase, the foiler is behind the buggy
on the tow rope. If the foiler leans or angles right, rope tension pulls the buggy
tail right — the buggy turns left. Vice versa for left. This is pure physics with
no code involvement. The foiler steers the buggy by body angle and rope tension.

**BREmote steering (manual):** The user operates the remote's steering toggle
directly. This is explicit user input. No autonomy involved. Active in normal
operation and optionally active during RTM as course correction (see below).

**Autonomous steering:** GPS and compass-guided heading corrections applied by
the firmware. Used exclusively in RTM (Return to Me) mode, where the buggy must
navigate back to the foiler's GPS coordinates. Default ON during RTM. The user
may apply BREmote steering during RTM to course-correct — this is called
course correction and is the only manual override during RTM.

FM (Follow Me) mode is designed to use autonomous steering when engaged — GPS-guided
  heading corrections to trail the foiler, combined with distance-based throttle gating.
  See FM section below. Note: FM autonomous steering is not yet implemented (Priority 9, future work).

## The Tow Phase
At the start of a session, the foiler holds the tow rope attached to the back of
the buggy. The buggy accelerates and pulls the foiler up to speed. During this phase:
- The buggy is ahead; the foiler is directly behind on the rope.
- Steering is via tow rope only (passive, see above). No BREmote steering needed.
- The user holds the throttle trigger to maintain speed.
- Releasing the trigger stops the motor immediately.

## The Whip / Wave Catch
When a wave approaches, the foiler uses the buggy's speed and rope tension to
slingshot ("whip") into the wave at an angle. The sequence:
1. Foiler angles toward the wave using rope tension.
2. Buggy momentum and rope snap accelerate the foiler onto the wave face.
3. Foiler releases the rope and begins foiling independently on the wave.
4. Rope goes slack. Buggy continues forward on its last heading, now unmanned.

This is the critical transition: from this moment, the foiler and buggy are
separated and moving independently.

## Post-Release Geometry
After the rope is released:
- The foiler is typically lateral to or ahead of the buggy, riding the wave.
- The buggy continues forward until the user releases the throttle trigger.
- The foiler may end up in any direction relative to the buggy — assume any
  geometry is possible after release.

## Follow Me (FM) Mode — Operational Model
FM is designed for the post-release phase. Once the foiler has caught the wave
and separated from the buggy, FM allows the buggy to trail the foiler.

**FM uses autonomous steering when engaged.** The buggy applies GPS-guided heading
corrections to maintain a configured lateral offset relative to the foiler (behind-left,
directly behind, behind-right — set via SPIFFS before the session). Throttle is gated
by follow distance: the buggy only moves when the foiler is beyond the minimum follow
distance, and throttle ramps gradually to avoid sudden engagement.

*Note: FM autonomous steering and GPS following are not yet implemented in firmware.
The current code supports FM mode selection (F0-F3) via gesture and displays the R5
proximity bar. Full autonomous FM following is Priority 9 (future work).*

**Throttle model (non-negotiable safety rule):**
- The user must hold the throttle trigger for the buggy to move — always.
- FM is a distance-based throttle gate. It can only reduce user throttle, never add.
- Hard stop zone (inner radius): if the buggy gets closer to the foiler than this
  threshold, throttle is cut to zero completely. The buggy stops. Hard limit,
  no override.
- Throttle ramp (activation gate): when FM activates (foiler exits the minimum
  follow distance), throttle ramps from 0 to the configured maximum over 3–4
  seconds. This prevents sudden full-speed engagement that could flip or wheelie
  the buggy. Maximum FM throttle is SPIFFS-configurable (default ~75%).
  Implementation TBD: ramp may trigger at the bubble boundary or on FM activation —
  to be decided in Priority 9.
- User releases trigger → motor stops immediately, regardless of FM state.

FM activates only after the foiler has cleared the minimum follow distance.

## Return to Me (RTM) Mode — Operational Model
RTM is used when the foiler has ridden far down the wave (or around a point) and
the buggy is stranded a significant distance away. The foiler activates RTM and
the buggy navigates back to the foiler's GPS coordinates using autonomous steering.

RTM requires large physical separation between foiler and buggy by definition.
RTM and FM are physically incompatible states:
- FM requires proximity (buggy following at safe distance behind foiler).
- RTM requires large separation (buggy returning from far away).
This geometric incompatibility reinforces the code-level mutual exclusion of FM
and RTM. If RTM arms while FM is active, FM must be explicitly disarmed and RX
must be notified (0xF2/0 packet) before RTM proceeds.

## Safety Philosophy (Non-Negotiable for All Code)
1. The buggy ONLY moves when the user physically holds the throttle trigger.
2. Autonomous modes (RTM, FM) can ONLY subtract from user throttle, never add.
3. Releasing the trigger stops the motor at the hardware level — no mode overrides this.
4. Manual control must always work even if RTM, FM, GPS, or compass systems fail.
5. Any code change that allows motor movement without active user throttle input
   must be rejected immediately before any further discussion.

## Edge Cases the System Does Not Solve
- Foiler falls and cannot hold the remote: trigger released, buggy stops.
- Buggy hit by a wave and changes heading: RTM self-corrects via GPS/compass;
  FM's intended design includes heading correction; current implementation is throttle-distance gating only (Priority 9 pending).
- Foiler ends up behind the buggy after a turn: hard stop zone prevents collision
  approach; FM has no directional awareness beyond distance.
- Rope wrap or entanglement: outside scope of software — operational procedure.
- Foiler whips into wave at full throttle while inside hard stop zone: buggy does
  not move. Foiler must clear the hard stop radius before throttle engages.

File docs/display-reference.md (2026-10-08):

# BREmote V2.5-Evo — Dot Display Reference

> **Partly outdated — the Follow-Me screens are changing.** This page, `display-reference.png`,
> `display-reference.svg`, `fm_bar_animation.gif` and `Dot_Matrix_Display_10x7_Render.html` show
> the **current master firmware** (bar only, no indicator dots). The new screens are in the
> **nightly** firmware on the [`fm-stations` branch](https://github.com/monterman/BREmote-V2/tree/fm-stations) (bleeding edge, under water
> testing, use at your own risk). See [Follow-Me screens — nightly](#follow-me-screens--nightly-fm-stations-branch)
> below and the [animated screens page](https://monterman.github.io/BREmote-V2/followme-screens.html).

## Follow-Me screens — nightly (`fm-stations` branch)

The FM pair of dots is C7 R3 + R4; R2 lights only while the buggy is coming to you.

| Screen | Dots (C7) | Numbers | R5 bar |
|---|---|---|---|
| waiting **Waiting** (armed; also parked auto-return) | R3 and R4 take turns every 200 ms | metres or `--` | scanner moving; blinking in place = not ready |
| following **Following** | R3 + R4 steady | metres | grows/shrinks from the centre |
| returning **Coming to you** (auto-return or return-to-me) | fills down: R2, R2+R3, R2+R3+R4, dark (200 ms steps) | metres counting down | anchored left, shrinking |
| **Stop / refused / fault** | — | `St` for 2 s, then the true state | — |

Numbers default to **metres to the buggy** (`fm_display_mode` 2): `X.X` under 10 m, whole metres
to 99, `FAR` beyond, `--` when not fresh. Blinking `St` = throttle input fault. The
distance-warning buzz (Pattern 8) and the station-step buzz are removed in the nightly;
`fm_warn_distance_m` only sets the bar's full scale. Full rider guide: [FOLLOW_ME_GUIDE.md](FOLLOW_ME_GUIDE.md).

## Hardware
Two 5×7 LED matrices side by side = 10 columns × 7 rows = 70 red LEDs
Driver: HT16K33 at I2C address 0x70

## Zone Map
| Zone | Location | Description |
|---|---|---|
| Digits | C0-C2 (left) + C4-C6 (right), R0-R4 | Two character display |
| Gap | C3, R0-R4 | Normally dark — separates digits; **R3** used as decimal dot during RTM/FM distance display (raised from R4 2026-07-25 for legibility) |
| GPS status | C7 R0 only | V2.5-Evo — see below |
| BLE status | C7 R1 only | V2.5-Evo SW55 — see below |
| Temperature | C8, R0-R4 | VESC temp, fills bottom→top |
| Signal | C9, R0-R4 | LoRa signal, fills bottom→top |
| R5 proximity bar | R5, C0-C9 | RTM/FM proximity indicator — NEW in P9 (see below) |
| Battery | R6, all cols | VESC battery, fills left→right |

## GPS Status Dot (C7 R0) — V2.5-Evo
Only visible when `gps_en = 1` in SPIFFS config.

| State | Display | Meaning |
|---|---|---|
| Solid green | ● | Valid GPS fix — ready for RTM/Follow-Me |
| Slow blink 1s | ○ ● ○ ● | Acquiring fix — waiting for satellites |
| Fast blink 250ms | ●●●● | GPS rejected — spoofing or bad signal alert |
| Off | (dark) | GPS disabled (`gps_en = 0`) |

## BLE Status Dot (C7 R1) — V2.5-Evo SW55
Controlled by `bt_dot_state`, driven by the DRV5032 Hall sensor on P_MAG (GPIO 9). Never solid — always blinking or off. Only visible when BLE is active.

| State | `bt_dot_state` | Display | Meaning |
|---|---|---|---|
| Off | `BT_DOT_OFF` | (dark) | BLE inactive — default on boot |
| Slow blink 1s | `BT_DOT_SLOW` | ○ ● ○ ● | BLE ready — toggled by short Hall hold (400 ms – 4.9 s) |
| Fast blink 250ms | `BT_DOT_FAST` | ●○●○ | BLE active — long Hall hold 5 s+ from slow state |

Releasing the magnet while `BT_DOT_FAST` → returns to `BT_DOT_OFF`. Short hold while `BT_DOT_SLOW` → toggles back to `BT_DOT_OFF`. BLE NUS + VESC Tool binary protocol released in master — field-confirmed 2026-05-16. Connect with VESC Tool (iOS/Android, free): scan for `BRemote-TX-XX`, connect, live gauges appear immediately.

## Decimal Dot (C3 R3) — Distance Display

**Changed 2026-07-25.** The dot is now a **true decimal point, always** — it no longer means "×100". Distance is shown in **metres only** this version (`dist_unit` is retained in SPIFFS; feet is parked and not rendered).

| Distance | Shows | Dot |
|---|---|---|
| < 1 m | `00` | no |
| 0–9.9 m | `X.X` — e.g. `1.7` = **1.7 m** | **yes**, C3 R3 |
| 10–99 m | `XX` whole metres — e.g. `17` = 17 m | no |
| ≥ 100 m | scrolling **`FAR`** | no |

- **Why it changed:** the dot previously meant ×100 above 100 m, so 170 m rendered as `1.7` and read as 1.7 m. That misread cost a rider control authority in the field. One meaning now: a dot is a decimal point.
- **Why `FAR` instead of a number:** the digit zone is two characters, so 100 m+ cannot render literally. A scrolling word is unmistakable against every static state (`L#`, `E#`, `F1/2/3`, `99`, `XX`, `--`). It scrolls in the digit zone only — the R5 proximity bar, C7 status dots and C8/C9 bars are untouched, and it does not flash.
- **Row position:** the dot sits at **R3** (raised one row from R4 on 2026-07-25 — on the bottom row it was hard to read). C3 is never written by `displayDigits()`, so the dot cannot collide with a digit at any row.
- Set via `displayBuffer[4] |= (1u << 3)` **after** calling `displayDigits()` (which clears R0–R5, R3 included). The kW readout uses the same row so the decimal point is at a consistent height everywhere.

## Vibration Feedback Patterns — V2.5-Evo P8
| Pattern | Feel | Trigger |
|---|---|---|
| 2 short (150ms) | Gentle | Low VESC battery warning (Pattern 1) |
| 5 short (150ms) | Urgent | LoRa connection lost OR GPS rejected (Pattern 2) |
| 5 long (500ms) | Emergency | Water detected inside buggy — E71 (Pattern 3) |
| 2 fast short (80ms) | Quick confirm | RTM arm / RTM disarm confirmed (Pattern 4) — NEW in P8 |

## Gesture Map — V2.5-Evo P8 (Breaking Change from P7)
| Gesture | Action | Notes |
|---|---|---|
| LEFT tap | Record tap (starts 3s combo window) | Sets up combo |
| RIGHT tap | Record tap (starts 3s combo window) | Sets up combo |
| LEFT hold 2s | Cycle telemetry display mode | Simple hold, no combo required |
| RIGHT hold 2s | Reserved — no action | Was: cycle display |
| RIGHT tap → LEFT hold 5s | Arm RTM (Return-to-Me) | Requires gps_en=1 and rtm_enabled=1 |
| LEFT tap → RIGHT hold 5s | Cycle FM mode (F0→F1→F2→F3) | Requires gps_en=1 and fm_override_enabled=1 |
| Boot: hold RIGHT | Pairing mode | RIGHT toggle held at boot (no throttle) enters pairing; RIGHT + throttle = wipe SPIFFS |
| Boot: hold LEFT | Calibration mode | LEFT toggle held at boot (no throttle) starts calibration; LEFT + throttle = force BLE session |

**Notes:**
- Lock feature removed in P8. System always boots unlocked.
- Throttle must be at 0 for long-press actions to fire.
- Tap window: 3s (`COMBO_WINDOW_MS`). Tap must occur before the hold begins.

## Display Modes (LEFT toggle hold 2s cycles through)

Cycle is `DISPLAY_MODE_COUNT = 7`. Modes with unavailable data (sentinel `0xFF`) are skipped automatically — `cycleDisplayMode()` loops until it finds an available mode.

| # | Code | Full name | Shows | Available when |
|---|---|---|---|---|
| 0 | tP | Temperature | VESC FET temp °C | VESC connected (`foil_temp != 0xFF`) |
| 1 | tH | Throttle | 0–99% trigger pull | Always |
| 2 | 5P | Speed | km/h, knots or mph per `speed_src` | TX GPS: always (`--` when no fix); RX GPS: fix required |
| 3 | PV | VESC Power | Battery-side power in kW, 1 decimal (e.g. `4.4` = 4400 W, capped 9.9 kW) | VESC connected (`foil_power != 0xFF`) |
| 4 | MA | Motor Amps | Motor current in whole amps (0–250 A) | VESC connected (`foil_motor_amps != 0xFF`) |
| 5 | Ub | Internal battery | TX LiPo voltage ×10 (e.g. `42` = 4.2 V) | Always |
| 6 | bA | VESC battery | Remaining % (0–100) | VESC connected (`foil_bat != 0xFF`) |

Default boot mode: `DISPLAY_MODE_THR` (mode 1). VESC timeout resets `foil_bat`, `foil_temp`, `foil_power`, `foil_motor_amps` to `0xFF`, hiding VESC-dependent modes automatically when the ESC is offline.

## Boot Sequence Timing — SW55

Total boot-to-padlock: ~4.5 seconds.

| Phase | Duration | Display |
|---|---|---|
| Firmware init | ~100 ms | Dark |
| VI splash | 250 ms | `VI` (version info) |
| Battery voltage | 1450 ms | Voltage reading (e.g. `42` = 4.2 V) — user reads battery before padlock |
| Unlock animation | ~700 ms | Paintbrush sweep R0→R6 (see below) |
| Operational | — | Default mode: `tH` (throttle %) |

## Unlock Animation — SW53 Paintbrush Sweep

`unlockAnimation()` runs at the end of boot. 3 frames, each ~230 ms.

**Frame sequence** — arrow descends row by row, each row stays lit (no inter-frame clear):

| Frame | Rows lit |
|---|---|
| 1 | R0 lit — top bar only |
| 2 | R0 + R1 + R2 lit — arrow growing downward |
| 3 | R0 → R6 fully lit — all rows painted |

Column rule: R0–R3 light C1–C8 (inner columns). R4–R6 also paint C0 and C9 (outer columns fully). Uses `|=` to accumulate pixels across frames — no `clear()` between frames, so each row stays lit as the arrow descends. Boot delay was 3 s before SW53; reduced to 500 ms.

## RTM / FM Active Display — V2.5-Evo P8 + P9
When `rtm_tx_active == true`, normal display is replaced by RTM info display.
Controlled by `rtm_display_mode` SPIFFS field:

| Mode | Shows | Notes |
|---|---|---|
| 0 (default) | Distance to TX | Unit-aware via `dist_unit` (see Distance Unit section below) |
| 1 | Speed | Same source as normal speed display (speed_src) |
| 2 | Alternating | Switches between distance and speed every 2.5s |

Distance is computed on RX side and sent via `telemetry.rtm_distance` (index 5).
Encoding: 0-99 = tenths of meter (0.0–9.9m); 100-254 = value-90 meters (100=10m, 199=109m).
TX decodes this value then routes it through `displayDistanceInUnits()` for unit conversion.

## Distance Unit Display (`dist_unit` SPIFFS field) — **superseded 2026-07-25**

> ⚠️ **The table below describes the OLD behaviour and no longer matches the firmware.** The ×100 dot was removed — see [Decimal Dot (C3 R3)](#decimal-dot-c3-r3--distance-display) above for what the display actually does now. Kept for historical reference only.
>
> **Current behaviour:** metres only for both `dist_unit` values (feet is parked, the field is retained in SPIFFS so a future version can implement it). `<1 m` → `00` · `0–9.9 m` → `X.X` with a **true decimal** dot at C3 R3 · `10–99 m` → whole metres · `≥100 m` → scrolling `FAR`.

<details><summary>Historical: the original P9 dist_unit ranges (removed)</summary>

| dist_unit | Unit | Range A | Range B (decimal dot active) | Minimum |
|---|---|---|---|---|
| 0 (default) | Metres / km | 1–99 m → whole metres ("01"–"99") | 100+ m → X.X km ("1.0"–"9.9") | <1 m → "00" |
| 1 | Feet / miles | 4–99 ft → whole feet ("04"–"99") | 100+ ft → X.X mi ("0.1"–"9.9") | <4 ft → "00" |

The dot lit only in Range B and meant ×100 — that is the ambiguity that was removed.
</details>

- Internal math is always metres. Unit conversion is display-layer only.
- `displayDistanceInUnits(float dist_m)` in Display.ino handles all cases.

## Full-Screen Confirmation Messages (P9 New — fontCompact3x7)
One-time blocking flashes rendered using the compact 3×7 font (all 10 columns × all 7 rows).
Source font: `docs/Dot_Matrix_Display_10x7_Render.html` — canonical pixel layout reference.

| Message | Columns | Trigger |
|---|---|---|
| *(removed)* `A rM` | — | Arm confirm replaced by unlock animation + `rn` 2s blink (removed in P9 Bug4) |
| `St` | large-font `displayDigits(LET_S, LET_T)` — not compact font | RTM disengages (any exit path) or pre-arm rejected |
| `FM 0` – `FM 3` | F(3) + M(3) + space(1) + 0-3(3) = 10 | FM mode cycled or FM arm confirmed |
| `E 7` | E(3) + space(1) + 7(3) = 7 columns | Water ingress error code E71 (display shows "E 7" — the "1" does not fit; blinks 250ms on/off, non-blocking) |

RTM exit shows `St` via `displayDigits(LET_S, LET_T)` (large-font, 2s). `showFullScreenMessage()` is still used for `FM 0`–`FM 3` and `E 7` (water ingress). FreeRTOS vibration task continues running during any blocking display hold.

## R5 Proximity Bar (P9 New)
Row R5 (`displayBuffer[6]`) is used as a proximity bar during RTM or FM.
Blink pattern: 1000 ms on / 500 ms off.

**RTM bar (square-root curve):**
- At RTM engage: `rtm_arm_dist_m` is captured from current `telemetry.rtm_distance`.
- Each update: `pixels = round(sqrt(current_m / arm_m) × 10)`, clamped 0–10.
- Bar fills C0→C9 (left to right). Shrinks from right as buggy approaches.
- At 100% distance (just armed): all 10 pixels lit.
- At 25% distance: 5 pixels lit (sqrt(0.25) = 0.5 × 10 = 5).
- At 0% (hard stop): 0 pixels — bar gone just before RTM disengages.

RTM Proximity Bar Animation

**FM bar (Priority 10 — center-expanding from C4+C5):**
- 2 pixels at C4+C5 = ideal following distance (sweet spot). Bar expands outward symmetrically as buggy gets closer. Dark when ≥30 m away. Full bar (C0-C9) = buggy right next to user.
- Implemented 2026-04-30 in `Display.ino:updateR5ProximityBar()` — replaced an earlier left-to-right linear fill. Center-expanding is the current and only implementation.

Following

*Nightly screen (`fm-stations` branch): the numbers are metres to the buggy, and the bar shrinks toward 2 dots as the buggy closes in
(here 15 m to 8 m). The text above describes the older master behaviour. See
[Follow-Me screens — nightly](#follow-me-screens--nightly-fm-stations-branch).*

**`rtm_arm_dist_m` variable:**
- RAM only — never written to SPIFFS.
- Captured at RTM engage (both single-squeeze and double-squeeze paths).
- Reset to `0.0f` inside `rtmDisengage()` on every exit path.
- If `0.0f` at bar render time, bar is suppressed (avoids divide-by-zero).

## Status / Mode Codes (TX dot display)
| Code | Meaning |
|---|---|
| rn | RTM armed — blinks during arm window; static 2s after arm confirmed |
| St | RTM disengaged or pre-arm rejected — large-font `displayDigits(LET_S, LET_T)`, 2s |
| FM 0 / FM 1 / FM 2 / FM 3 | FM mode confirmed — full-screen 2s flash (fontCompact3x7) |
| -- | ET error or no-data — auto-clears after 3s |

## Error Codes (TX dot display)
| Code | Meaning |
|---|---|
| EP | Not paired |
| EC | Not calibrated |
| E- | Error (code too large for display) |
| E71 | Water ingress detected (triggers 5 long buzzes) |
| E5V | Config version mismatch — re-flash or clear SPIFFS |
| U5b | USB serial mode active |
| XX | Power saver mode — remote going to sleep |

## New SPIFFS Fields — V2.5-Evo P8 (TX-side)
| Field | Range | Default | Description |
|---|---|---|---|
| `rtm_display_mode` | 0-2 | 0 | RTM/FM active display: 0=distance, 1=speed, 2=alternating 2.5s |
| `fm_warn_distance_m` | 50-1000m | 150 | TX-RX distance for FM proximity warning vibration. *Nightly: no vibration; bar full scale only (50-164 m).* |
| `rtm_steer_exit_on_input` | 0-1 | 1 | 1=steering exits RTM; 0=blend/correction mode |
| `rtm_max_runtime_s` | 0-300s | 0 | Max RTM runtime; 0=disabled (safety gates handle scenarios) |

## New SPIFFS Fields — V2.5-Evo P9 (TX-side)
| Field | Range | Default | Description |
|---|---|---|---|
| `dist_unit` | 0-1 | 0 | Distance display unit: 0=Metres/km, 1=Feet/miles. Internal math always in metres. |

**No sizeof change:** `dist_unit` fills the 2-byte tail padding left by P8.1. sizeof(confStruct) stays 128. No SPIFFS reset on first P9 flash — old configs read 0 here (tail padding was zero), which is the correct Metres default.

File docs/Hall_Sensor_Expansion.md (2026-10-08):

# Hall Sensor Expansion — Magnet Gestures on P_MAG (GPIO 9)

## Background — Hall sensors are already in BREmote V2

BREmote V2 (and V2.5-Evo) already use Hall-effect sensors throughout the handheld TX:

| Sensor | Purpose |
|---|---|
| Hall-effect **throttle** | Trigger finger position → throttle value 0–100% |
| Hall-effect **toggle** | Left/right toggle switches → steering, gear, gesture combos |
| Hall-effect **power switch** | Main on/off switch — no mechanical contacts |

These are the original LudwigBre design choices. Hall sensors are contactless, waterproof, and immune to corrosion — ideal for a device used near water.

---

> **Installing for the first time?** See the [step-by-step install tutorial](Hall_Sensor_Install_Tutorial.md) — includes hardware options, soldering notes, and troubleshooting.

## The Expansion — a fourth sensor for magnet gestures

V2.5-Evo adds an optional fourth Hall sensor on **P_MAG (GPIO 9)**. Touch a small magnet (on your
wrist or glove) to the outside of the remote and you can **arm Follow-Me** or **start
Return-to-Me** without reaching for the toggles, even while you're being towed.

The sensor is **optional**. Everything also works from the toggles.

**Sensor used:** TI **DRV5032** (unipolar Hall-effect switch, 3.3 V, SOT-23). Easier-to-solder
alternatives are listed in the [install tutorial](Hall_Sensor_Install_Tutorial.md#hardware-options).

> ⚠️ **GPIO 9 is an ESP32-C3 boot (strapping) pin. Never power the remote on with the magnet
> against it.** A magnet holding GPIO 9 low at power-up puts the chip into download mode and the
> remote won't boot (dark screen, no buzz). Take the magnet away, power on, then use it. The
> firmware can't prevent this: the chip reads the pin before any firmware runs.

### Why GPIO 9

GPIO 9 on the ESP32-C3 (HT-CT62) is a free input with an internal pull-up. It was unused in the
original BREmote V2 design and sits near the existing Hall sensor circuitry on the PCB.

---

## Wiring

Connect the DRV5032 between the TX board and the enclosure wall (or a small external pocket):

```
DRV5032 VCC  → 3.3V
DRV5032 GND  → GND
DRV5032 OUT  → GPIO 9 (P_MAG)
```

The output is active-low — it pulls low when a magnet is present, floats high when no magnet. The internal pull-up on GPIO 9 handles the idle state; no external resistor needed.

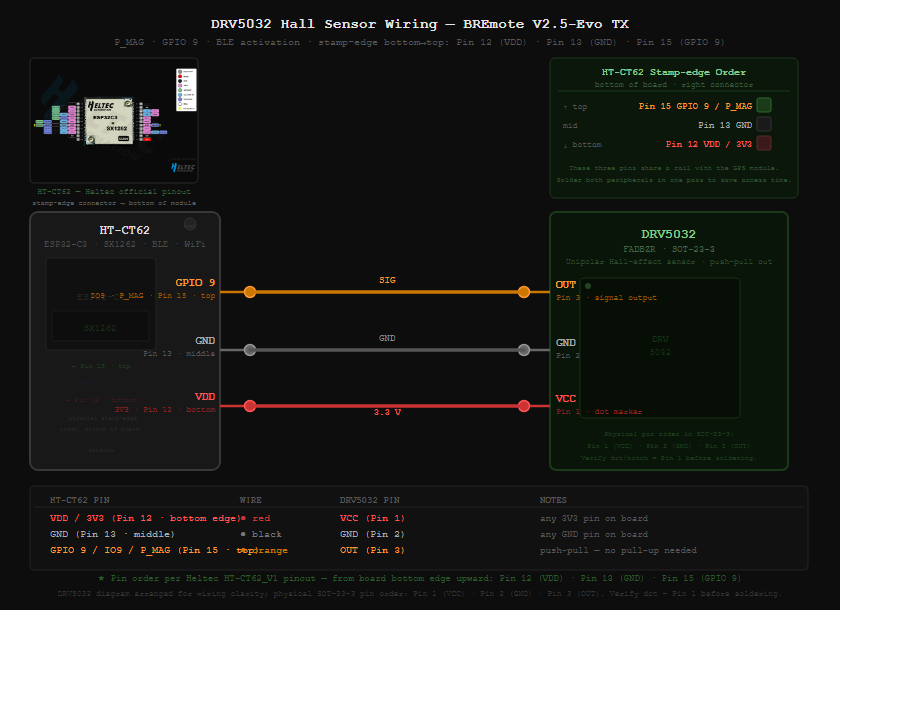
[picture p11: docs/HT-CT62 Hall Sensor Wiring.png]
HT-CT62 Hall Sensor Wiring


*[SVG version](HT-CT62%20Hall%20Sensor%20Wiring.svg)*

---

## Firmware behaviour — `mag_mode` (TX setting)

`mag_mode` picks what the magnet does. Default **0** (off / sensor not fitted).

### Mode 4 — tap and hold *(new in the upcoming release)*

*In the nightly builds on the [`fm-stations` branch](https://github.com/monterman/BREmote-V2/tree/fm-stations) (bleeding edge,
use at your own risk); it moves to master gradually after more water testing.*

| Magnet | Result |
|---|---|
| **Tap** (under about 0.6 s) | Follow-Me not armed → **arms it** at your stored station. Following → **steps to the next station** (the stations in `mag_fm_set`). Works **with the trigger held**, so you can arm on the rope. After a step, taps for the next second are ignored. |
| 0.6 s – 2.5 s | Nothing (a gap so a tap and a hold can't be confused) |
| **Hold 2.5 s, trigger released** | Two medium pulses: let go to start the **manual Return-to-Me** ("rn", then confirm with the trigger). With the trigger held the hold is ignored. If return-to-me can't start (switched off, no GPS) you get **St**. |

Mode 4 never switches Follow-Me off. Use the toggle gesture for that. See the
[Follow-Me guide](FOLLOW_ME_GUIDE.md) for the full picture.

### Modes 1–3 — hold and release *(current master firmware)*

The action happens when you **take the magnet away**:

| `mag_mode` | Hold | Result |
|---|---|---|
| 1 | about 2 s (one short pulse) | arm / disarm Follow-Me |
| 2 | about 2 s | arm / disarm Return-to-Me |
| 3 | about 2 s → Follow-Me, about 5 s → Return-to-Me | two-tier gesture |

In the upcoming release the Return-to-Me hold in modes 1–3 also needs the trigger released.

### Mode 0 — the older BLE role

With `mag_mode` 0 and `bt_enabled = 1`, the magnet keeps its first job: switching BLE on for the
session (BT dot on the screen).

| Gesture | Hold Duration | Result |
|---|---|---|
| Short hold | 400 ms – 4.9 s | BT dot → slow blink (BLE ready / advertising) |
| Long hold | 5 s+ (from slow state) | BT dot → fast blink (BLE active) |
| Short hold (from slow) | 400 ms – 4.9 s | BT dot → off (BLE off) |

With `mag_mode` 1–4 the magnet is used only for Follow-Me / Return-to-Me, and the BT dot shows the
real BLE state. `bt_enabled = 2` (always on) starts BLE 5 s after boot either way.

---

## Config

Set via the Web Serial Config Tool or serial:

```
?set mag_mode 4
?save
```

| Setting | Values |
|---|---|
| `mag_mode` | 0 off · 1 FM · 2 RTM · 3 FM + RTM · 4 tap = FM / station, hold = return-to-me *(upcoming)* |
| `mag_fm_set` | which stations a tap steps through: bit 0 = F1, bit 1 = F2, bit 2 = F3; 7 = all *(upcoming)* |
| `bt_enabled` | 0 BLE off · 1 magnet/session (mode 0 only) · 2 always on |

---

## No Sensor? Use the Toggles

- Follow-Me: **LEFT tap, then RIGHT hold** (while floating).
- Return-to-Me: **RIGHT tap, then LEFT hold** (trigger released).
- BLE for one session: hold **Throttle + LEFT toggle** while powering on.

---

## Source Reference

```
Source/V2_Integration_Tx/
  Hall.ino               — runMagGesture(): the magnet gestures (mag_mode)
  V2_Integration_Tx.ino  — P_MAG polling and the BT dot (mag_mode 0)
  BREmote_V2_Tx.h        — P_MAG pin, mag_mode / mag_fm_set fields
  BLE.ino                — bt_session_forced flag, bleTelemetryLoop() bt_dot check
```

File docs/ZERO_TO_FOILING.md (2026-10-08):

# Zero → Foiling

**BREmote V2.5-Evo — from an unflashed board to Follow-Me on the water.**

One linear path. Follow it in order; each phase assumes the one before it passed.

The public firmware ships **fully unbound and unconfigured** — not paired, neutral compass
calibration, logging off. Nothing personal ships in the image. You set it up yourself from the
serial console and the on-device web portal.

Steps are tagged **[DESK]** · **[BENCH]** · **[WEB PORTAL]** · **[WATER]**. Anything marked
*(tweak-later-OK)* is safe to leave alone until after your first sessions.

---

## THE SAFETY MODEL — read first, it never changes

1. **The buggy moves only while you physically hold the throttle trigger.** No throttle input = no motor, ever.
2. **Follow-Me and Return-to-Me can only *steer* and only *subtract* throttle — never add it.** There is no loiter, no station-keeping, no self-driving.
3. **Releasing the trigger stops the buggy instantly, at the hardware level, in every mode.**
4. **Manual control always works**, even if GPS / compass / radio fail.
5. **GPS distance is an ASSIST, not the authority.** At close range GPS can read ~15 m off. Trust your eyes (line-of-sight), not the number. This is why the follow distance ships deliberately generous.
6. **FM and RTM are mutually exclusive** — arming one disarms the other.
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

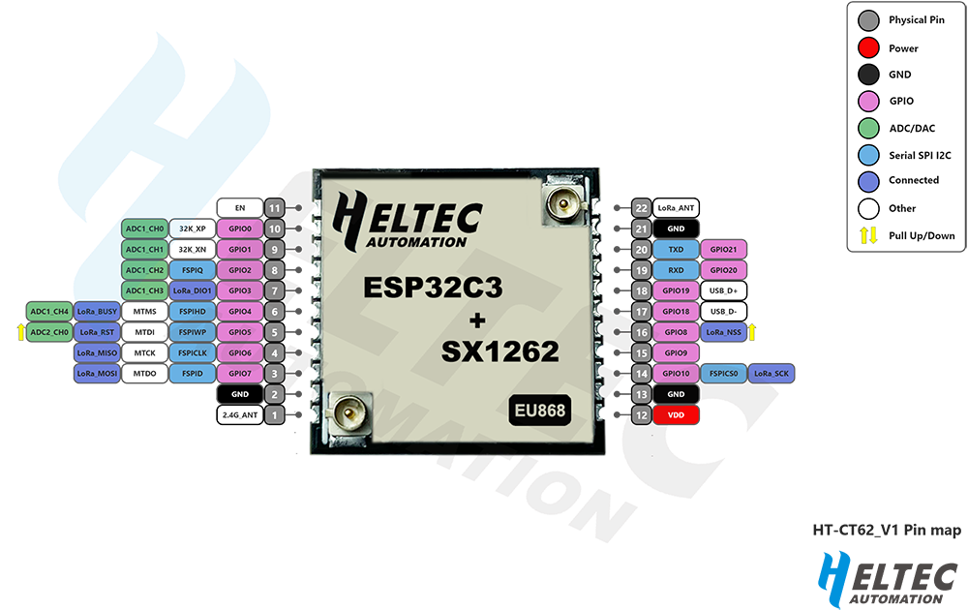
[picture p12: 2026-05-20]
docs/HT-CT62-board.png

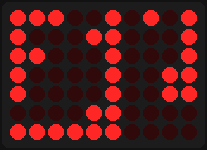
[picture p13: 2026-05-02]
docs/fm_bar_animation.gif

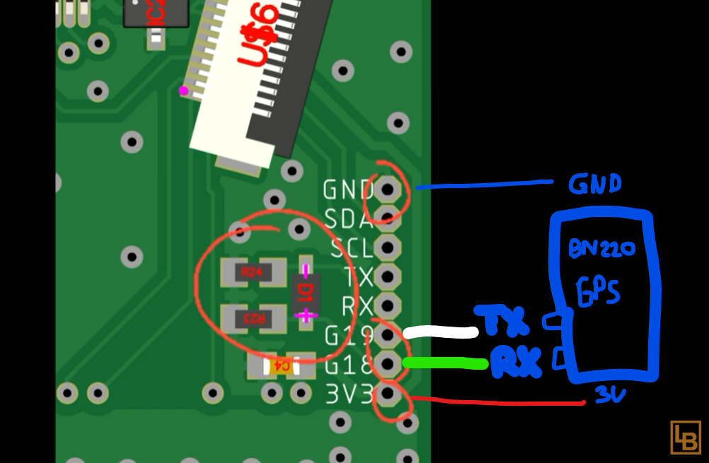
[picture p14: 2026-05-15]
docs/TX bremote pins to gps 18-19.png

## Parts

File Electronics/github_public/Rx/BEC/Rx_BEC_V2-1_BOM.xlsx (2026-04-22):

Comment | Designator | Footprint | JLCPCB Part #（optional）
100uF 35V RVE100UF35V67RV0072 | C3 | CPOL-EU153CLV-0605 | C2836437
10uF 100V RVT2A100M0607 | C2, C4, C5 | CPOL-EU153CLV-0605 | C86606 | C72482
10uH 900mA CBC3225T100KR | L1 | R-EU_R1210 | C90321
1uF 100V HT2A1R0M0405 | C1 | CPOL-EU153CLV-0405 | C87863 | C90265, C2977463
470 | R1, R2, R3 | R-EU_R0805
WJ126V-5.0-2P | U$1 | WJ126V-5.0-2P | C8404

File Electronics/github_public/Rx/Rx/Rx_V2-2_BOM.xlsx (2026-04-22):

Comment | Designator | Footprint | JLCPCB Part #（optional）
0R | R_ANT | R-EU_R0402
100 | R7, R8 | R-EU_R0603
100n | C1, C2, C3, C4, C7, C8, C9, C10, C13, C16 | C-EUC0603
10k | R4, R10, R11, R15, R20, R24, R28, R30, R31, R32, R33, R34, R35, R36, R37 | R-EU_R0603
120k | R1 | R-EU_R0603
1M | R22 | R-EU_R0603
1N4148WS | D2, D5 | 1N4148WS | C2128
1k | R9, R14, R38, R39, R40, R41, R42 | R-EU_R0603
1u | C5, C6, C12 | C-EUC0603
2.2uF | C11 | C-EUC0603
220 | R25, R26 | R-EU_R0603
3k3 | R12 | R-EU_R0603
4k7 | R13, R16, R17, R18 | R-EU_R0603
5k1 | R5, R6 | R-EU_R0603
LQW15AN6N8G00D | L_ANT1 | R-EU_R0402 | C82919
74HC4052PW,118 | IC6 | 74HC4052PW,118 | C19723807
AMS1117-3.3 | IC2 | AMS1117-3.3 | C6186
AO3400A | Q3, Q4 | AO3400A | C20917
AW9523BTQR | IC1 | AW9523BTQR | C148077
BSS138 | Q1, Q2, Q5, Q6, Q7 | BSS138 | C5224260
CH340K | AC1 | CH340K | C968586 | alt C18208922
EL3H7_TA_-VG | IC3, IC4, IC5 | EL3H7_TA_-VG | C32565
LM66100DCKR | D6, D7, D8 | LM66100DCKR | C2869734
MMBT5551 | T1 | BC847B-NPN-SOT23-BEC | C2145
KT-0603R | LED2, LED3 | LEDCHIP-LED0805 | C2286
P6SMB6.8CA | D1, D3, D4 | P6SMB6.8CA | C78395
RFANT3216120A5T | R2 | R-EU_R1206 | C127629
BWSMA-KE-Z001 | U$1 | SMA_5.08_1.4 | C496549
TS-1187A-B-A-B | S1, S2 | TS-1187A-B-A-B | C318884
TYPE-C-31-M-12 | J1 | TYPE-C-31-M-12 | C165948

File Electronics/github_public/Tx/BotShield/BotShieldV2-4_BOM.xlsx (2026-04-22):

Comment | Designator | Footprint | JLCPCB Part #（optional）
100 | R4 | R-EU_R0603
100n | C5, C6, C9, C10, C13, C14, C15, C17, C20 | C-EUC0603
10k | R10, R11, R13, R14, R15, R16, R17, R22 | R-EU_R0603
10n | C12 | C-EUC0603
10u | C7, C8, C16 | C-EUC0603
1k | R3, R7, R12, R20, R21 | R-EU_R0603
1u | C18, C19 | C-EUC0603
2.2uF | C11 | C-EUC0603
3k3 | R6, R18 | R-EU_R0603
4k7 | R5, R8, R9 | R-EU_R0603
6k8 | R19 | R-EU_R0603
74LVC1G14GW,125 | IC3 | 74LVC1G14GW,125 | C265125
ADS1115IDGSR | IC5 | ADS1115IDGSR | C37593
AO3400A | Q2, Q3, Q4, Q5 | AO3400A | C20917
AO3401A | Q6 | AO3401A | C15127
CH340K | AC1 | CH340K | C18208922 | alt C968586
DW01A | IC4 | DW01A-G | C2927799 | alt C18164398 or C351410
FPC-05F-14PH15 | U$11 | FPC-05F-14PH15 | C2856818
FS8205A | Q1 | FS8205A | C2830320
ME6211C33M5G-N | IC6 | ME6211C50M5G | C82942
OH49E-S | IC8 | DRV5055A3QDBZR | C85573
SDFL2012Q2R7KTF | L2 | SDFL2012Q2R7KTF | C1046
TP4056 | IC7 | TP4056-42-ESOP8 | C725790

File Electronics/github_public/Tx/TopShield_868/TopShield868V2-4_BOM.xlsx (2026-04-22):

Comment | Designator | Footprint | JLCPCB Part #（optional）
0R | R1 | R-EU_R0603
100n | C1, C3, C4 | C-EUC0603
10k | R23 | R-EU_R0603
np | R24 | R-EU_R0603
LQW15AN4N3B00D | L_ANT | R-EU_R0402 | C91625
GJM1555C1H4R0BB01D | C_ANT | C-EUC0402 | C161323
1u | C2 | C-EUC0603
LQW15AN6N8G00D | L_ANT1 | R-EU_R0402 | C82919
FPC-05F-14PH15 | U$6 | FPC-05F-14PH15 | C2856818
HT16K33A-24SSOP | U$1 | HT16K33A | C5444736 | alt C5444738
OH49E-S | IC1 | DRV5055A3QDBZR | C85573
RFANT3216120A5T | R2 | R-EU_R1206 | C127629
SDFL2012Q2R7KTF | L1 | SDFL2012Q2R7KTF | C1046
UHE4913G-AE3-R | IC2 | DRV5055A3QDBZR | C86815

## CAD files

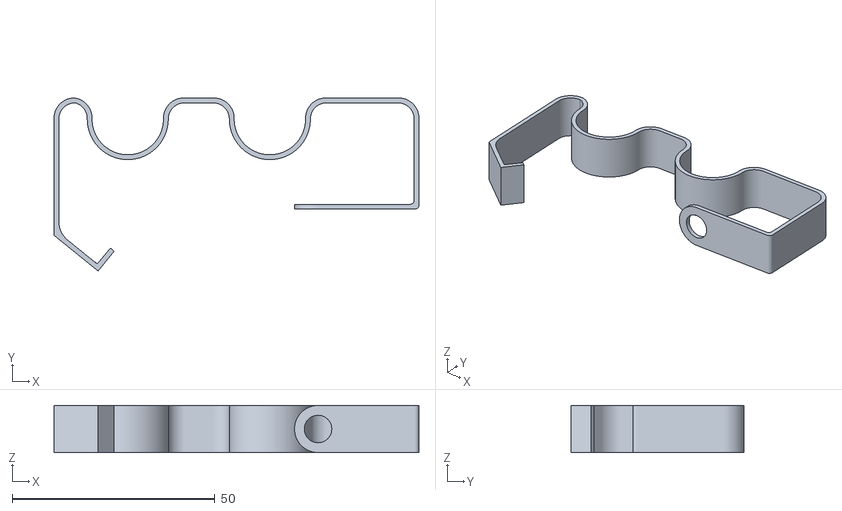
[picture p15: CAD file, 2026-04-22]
Mechanics/Assy_Clamp.stl
90.0 x 42.7 x 11.6

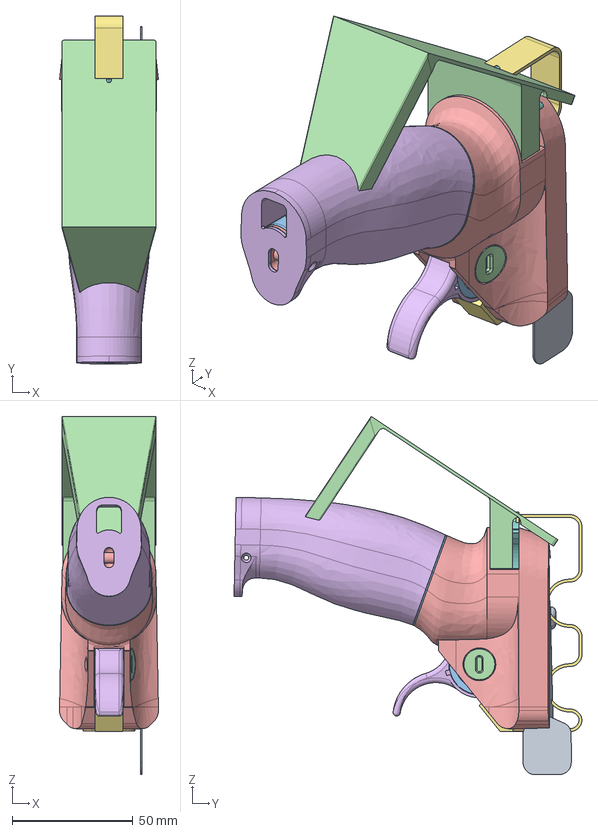
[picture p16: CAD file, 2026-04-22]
Mechanics/Complete.step
41.0 x 144.3 x 148.6 mm
Switch_Side
V2_Spring_Metal v1

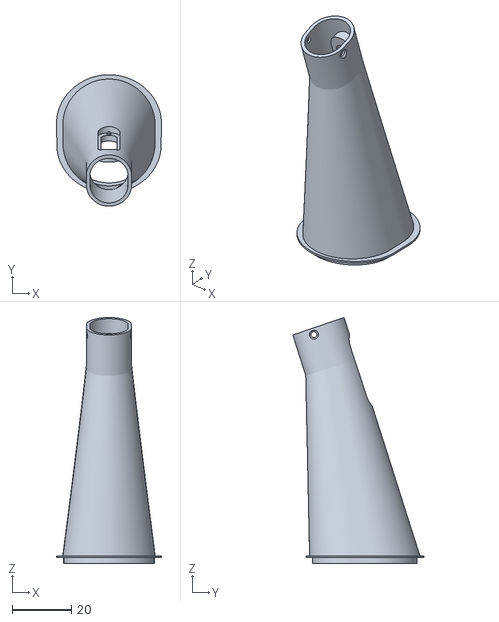
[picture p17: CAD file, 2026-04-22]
Mechanics/InsideHandle.stl
35.3 x 44.3 x 82.9

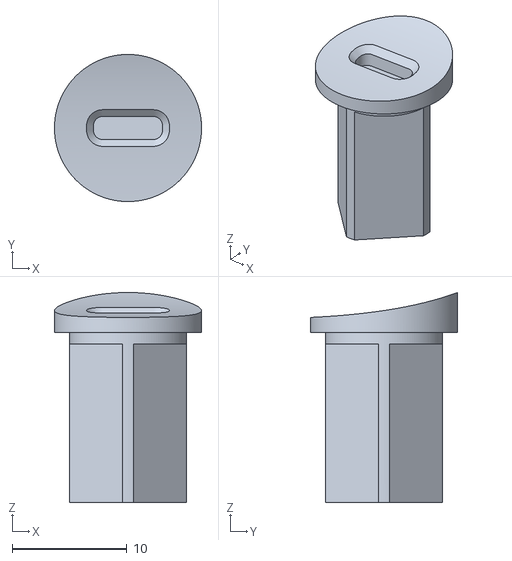
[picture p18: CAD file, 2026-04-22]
Mechanics/Trigger_Pin.stl
12.8 x 12.8 x 18.3

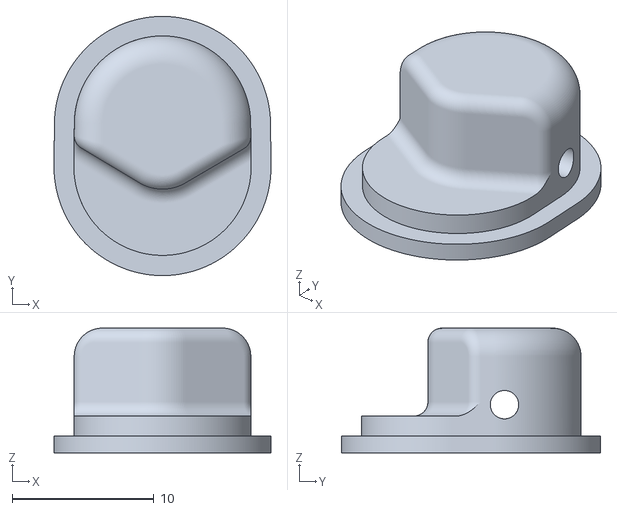
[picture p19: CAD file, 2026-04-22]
Mechanics/Endcap_Handle.stl
15.3 x 18.3 x 8.80

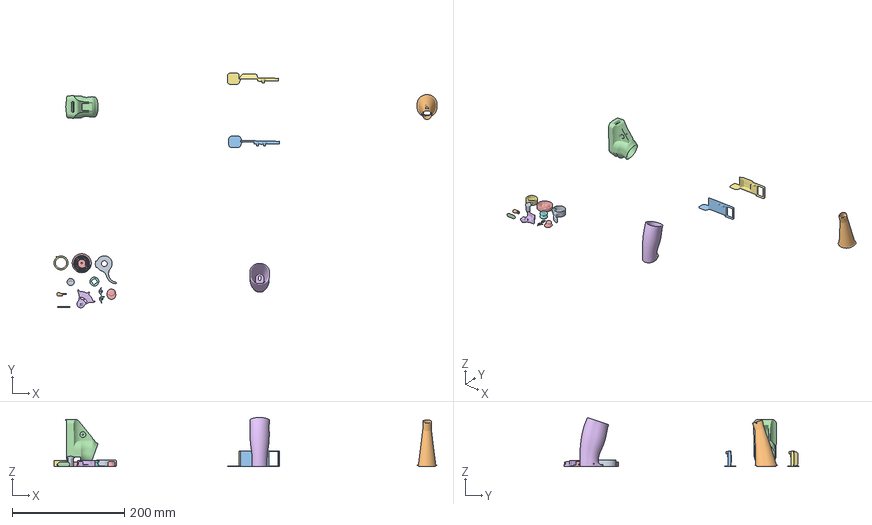
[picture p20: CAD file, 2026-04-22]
Mechanics/AllPartsSliced_V2-1.3mf
681.3 x 417.5 x 87.2 mm
XX_Trigger_export_steep.stl
XX_InsideHandle.stl
XX_Top_Cover.stl
Top.stl
Stator_export.stl
Rotor.stl
XX_Spring_Idle_Mod_Rot (1) (1).stl
XX_Spring_Idle_Mod_Rot (1).stl
XX_Trigger_Pin_Export.stl
Switch.stl
Switch_Cover.stl
FrontPlate.stl
Endcap_Handle.stl
HandleSmall.stl
Top_Cover_GPS.stl
Switch_Cover_GPS.stl

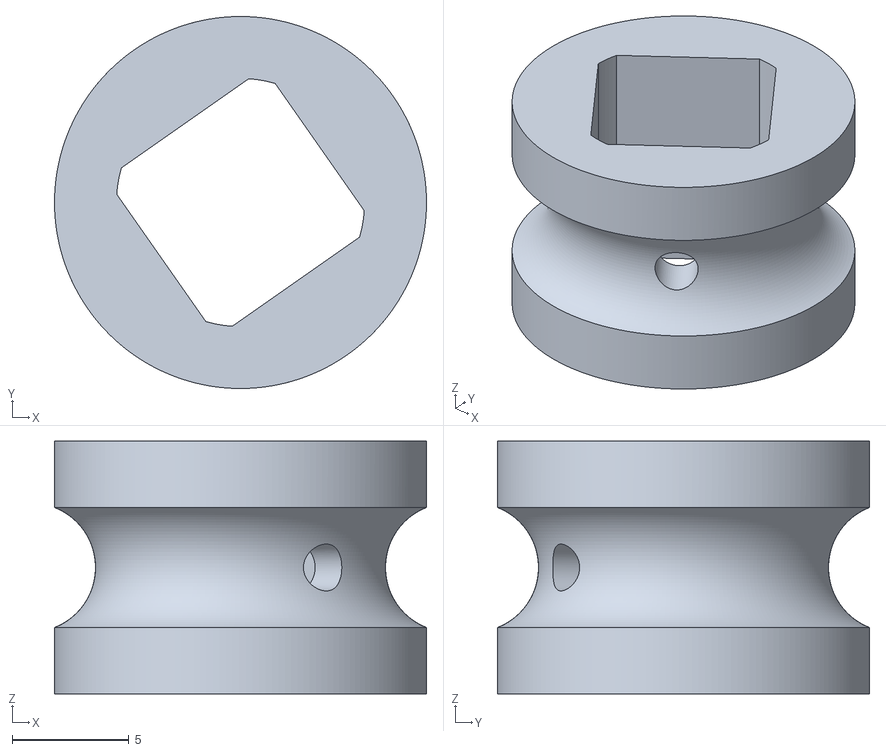
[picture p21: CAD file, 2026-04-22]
Mechanics/Trigger_Spring_2.stl
15.9 x 15.9 x 10.8

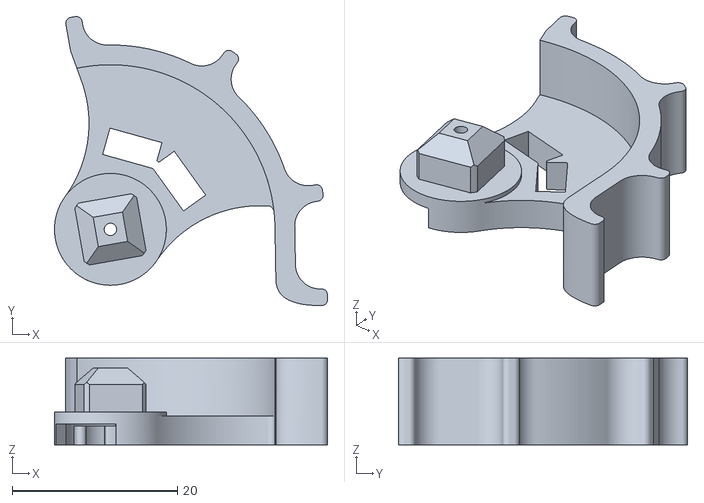
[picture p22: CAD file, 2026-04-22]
Mechanics/Rotor_sidegrip.stl
33.0 x 35.0 x 10.5

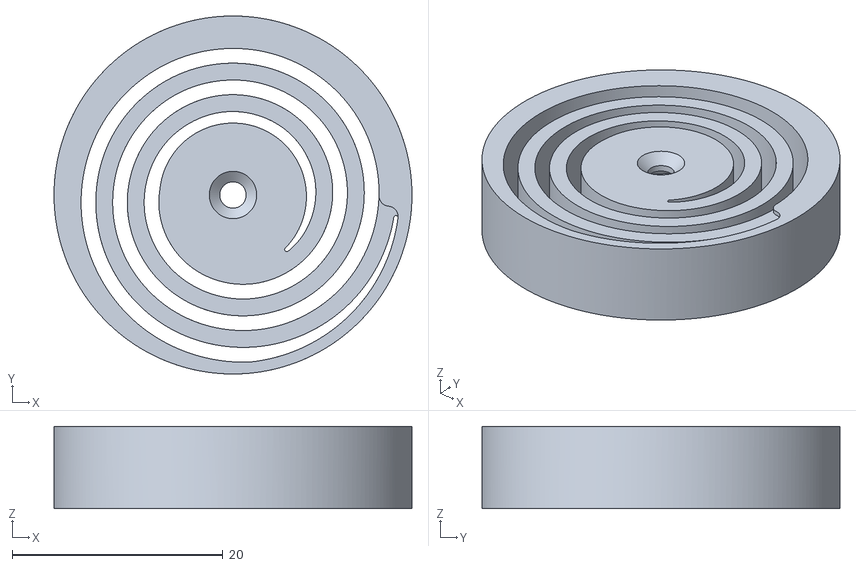
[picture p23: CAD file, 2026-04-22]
Mechanics/Stator.stl
34.0 x 34.0 x 7.80

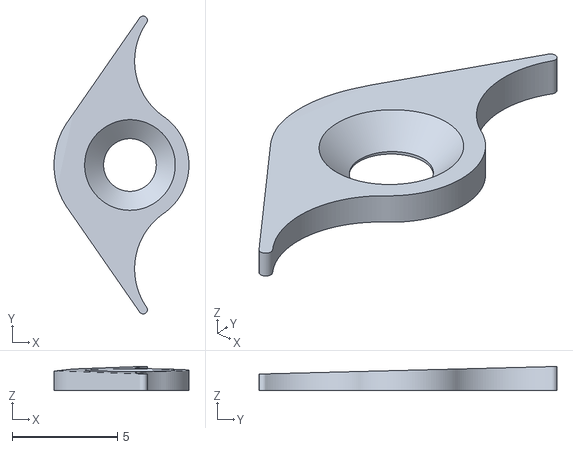
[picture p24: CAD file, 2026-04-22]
Mechanics/Switch_Cover_noGPS.stl
6.40 x 14.1 x 1.14

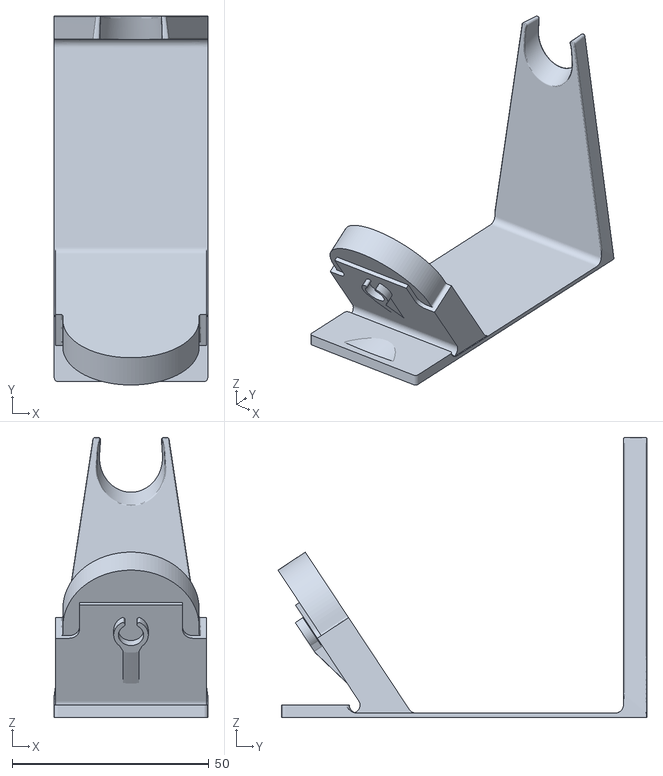
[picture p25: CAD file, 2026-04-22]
Mechanics/FillStand.stl
39.0 x 93.7 x 71.2

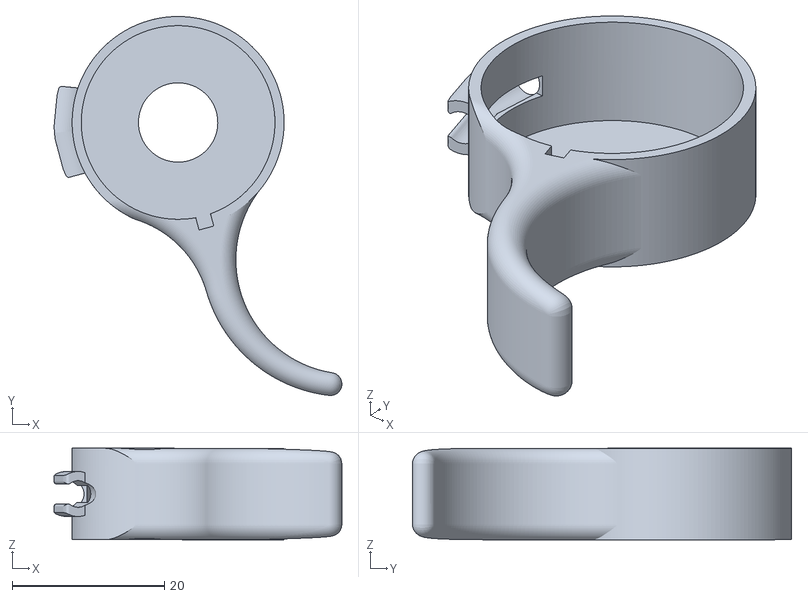
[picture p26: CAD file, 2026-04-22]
Mechanics/Trigger.stl
37.7 x 49.7 x 12.0

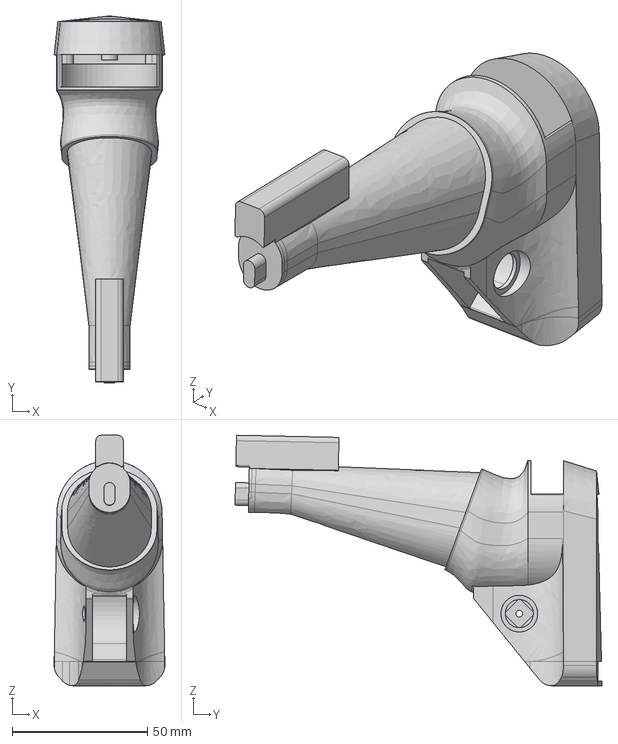
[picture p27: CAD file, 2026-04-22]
Mechanics/HandleCutter.step
41.0 x 135.9 x 92.8 mm

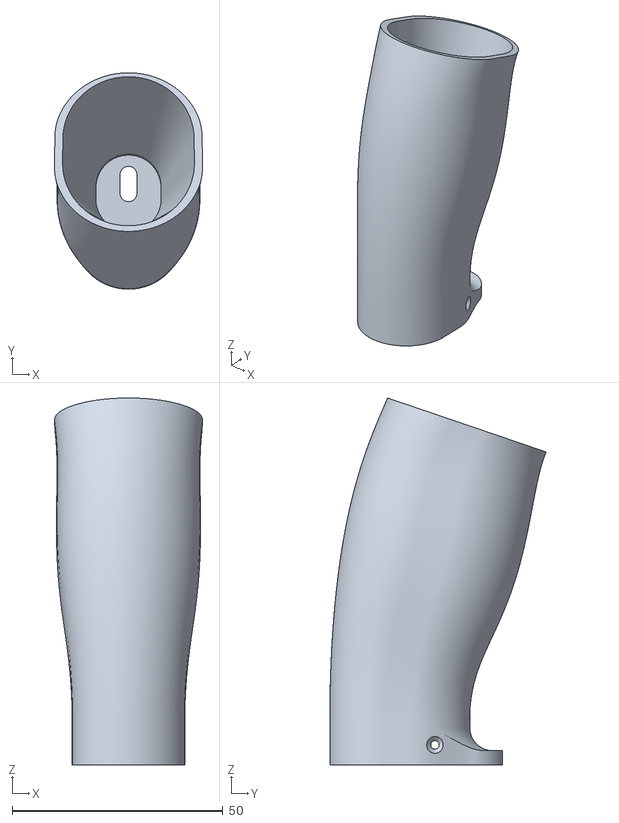
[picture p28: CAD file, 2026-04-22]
Mechanics/HandleSmall.stl
35.2 x 51.4 x 87.2

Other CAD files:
Mechanics/Switch_Cover_GPS.stl
Mechanics/Trigger_Spring_1.stl
Mechanics/Top.stl
Mechanics/Switch.stl
Mechanics/FrontPlate.stl
Mechanics/Rotor.stl
Mechanics/Top_Cover_GPS.stl
Mechanics/Top_Cover_noGPS.stl

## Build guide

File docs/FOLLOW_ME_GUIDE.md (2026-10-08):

# Follow-Me (FM) — Rider's Guide

**BREmote V2.5-Evo** · tow buggy / eFoil remote

> **🌙 nightly firmware.** These docs, the setup wizard and the new screens match the
> **nightly** firmware on the [`fm-stations` branch](https://github.com/monterman/BREmote-V2/tree/fm-stations), not the firmware on
> master. Nightly = bleeding edge, under water testing, use at your own risk. Binaries are in
> the `latest-FM-stations` folders.

> **Firmware status.** This guide describes the **upcoming release**: the new screens,
> auto-return, the magnet tap and the front stations. It is **in the nightly builds on the
> [`fm-stations` branch](https://github.com/monterman/BREmote-V2/tree/fm-stations)** now, and **moves to master gradually after more
> testing**. Firmware on
> master today still uses the older screens (a bar only, no dots).
>
> Flash the remote and the buggy **together**: the new screens need both sides on the new firmware.
> Download your logs from the buggy before you flash it (see the README, *log format 3*).

**See it move:** [the Follow-Me screens page, with a glance quiz](https://monterman.github.io/BREmote-V2/followme-screens.html)
· **Set it up:** [setup wizard](https://monterman.github.io/BREmote-V2/setup-wizard.html)

---

## 1. What Follow-Me does

After the whip, once you've let go of the rope and you're riding the wave, Follow-Me makes the
**buggy trail you** at a set distance and side, steering itself, so you can watch the wave instead
of the remote.

It is **not** an autopilot. The rule never changes:

> **The buggy moves only while you hold the throttle trigger. Follow-Me only *steers* and only
> *reduces* throttle. It can never add throttle, and letting go of the trigger stops the buggy.**

---

## 2. Safety philosophy

These rules decide every Follow-Me and return feature. They are why the screens and buzzes look the
way they do.

1. **Manual always wins.** If the GPS, the compass or any automatic mode fails, the automation
   switches itself off and hands control back to you. You can always drive the buggy home by hand.
   Manual throttle and steering never depend on GPS, compass, logging or the screen.
2. **"St" is the one "not working" signal.** Something stopped, a mode was refused, a fault: you
   always get **St** on the screen, and a long buzz if you didn't cause it. No other refusal codes
   to learn.
3. **The screen shows only what the buggy confirms.** The remote draws "following" or "coming to
   you" only when the buggy itself reports it. Old data is never shown as live: a distance that is
   not fresh shows `--`, not a frozen number.
4. **Auto-return waits for the rider.** A parked buggy waits while you surf, swim or pump back.
   "Waiting" means a squeeze **will** bring it. If it can't, you get **St** instead of a waiting
   screen.
5. **Arrival keeps a throttle cap until one full release.** When a returning buggy reaches you,
   steering is yours again at once, but the throttle stays limited until you let go of the trigger
   completely once. A buggy that arrives while you're at full throttle can't run into you.

---

## 3. Before you ride

Follow-Me needs:

- a **paired** remote and buggy, both on the new firmware;
- **GPS fix on both**;
- a healthy **radio link**, with telemetry flowing back to the remote;
- a buggy that knows its heading: a **calibrated compass** (`?compasscal`), or GPS course when the
  buggy is moving.

You can *arm* before all of that is ready. The screen shows "not ready" (see §6) and Follow-Me
will not *engage* until it is.

---

## 4. Arming — telling the buggy "I want you to follow"

Arming is a **statement of intent**. It does not move anything.

### 4a. The toggle (works while floating)

1. **LEFT tap, then RIGHT hold** (about 3 s, set by `fm_hold_duration_s`).
2. The remote shows **F1 / F2 / F3** and buzzes **two short taps** = armed.
3. Repeat the gesture before your first squeeze to step the station: **F1 → F2 → F3 → F1**.
   It never lands on "off" by accident.

To switch Follow-Me **off**, make the same gesture after you have ridden. The toggle is your
steering while the trigger is held, so it can't arm mid-tow. That's what the magnet is for.

### 4b. The magnet (works during the tow)

If your remote has the optional Hall sensor ([install tutorial](Hall_Sensor_Install_Tutorial.md))
and `mag_mode` = **4**:

- **Tap** the magnet (under about 0.6 s): arms Follow-Me at your stored station. While following,
  each tap **steps to the next station**. After a step, taps for the next second are ignored, so
  one wobbly tap can't skip two stations.
- **A tap works with the trigger held.** If you forgot to arm, you can do it on the rope.
- In mode 4 the magnet never switches Follow-Me off. Use the toggle gesture for that.

Older magnet modes 1-3 still work (hold about 2 s for Follow-Me, about 5 s for return-to-me, action
on release).

**The arm stays on for the whole session** by default (`fm_arm_timeout_s` = 0). A slow takeoff, a
wait or a swim won't lose it.

---

## 5. The whip — how Follow-Me engages

Follow-Me engages only when **both GPS units prove you have separated**, not on a timer:

1. You're armed, trigger held.
2. You whip and pull away from the buggy.
3. Once you've been **beyond the engage distance for 2 seconds**, the buggy starts following.

Keep the trigger held; no release step is needed.

- **Whip yourself to the side** (classic): you slingshot past and ride away.
- **Steer the buggy away**: keep the trigger and steer the buggy to its side so *it* peels off
  while you carry straight on. Steering during this moment doesn't cancel the arm.

---

## 6. Reading the remote — the new screens

*New in the upcoming release.* Three looks to learn. The bottom of the screen is you.

| Screen | What you see | Meaning |
|---|---|---|
| Waiting | **One dot hopping** between two places, bar scanning | **Waiting.** Armed and ready for your whip. A parked buggy waiting for you to summon it (auto-return) looks **exactly the same**. If the bar **blinks in place** instead of scanning, it's not ready yet (GPS or link still coming). |
| Following | **Two steady dots**, bar grows and shrinks with distance | **Following you.** |
| Returning | **The dot column fills down from the top**, metres count down, bar shrinks from the left | **Coming to you** (auto-return or manual return-to-me). |

**The numbers** are the **metres between the remote and the buggy** (`fm_display_mode` 2, the new
default): `X.X` under 10 m, whole metres up to 99 m, `FAR` beyond that, and `--` when there's no
fresh distance.

**"St"** for 2 seconds = something stopped or was refused. Then the screen shows the true state:
the normal screen (Follow-Me off) or the waiting screen (still armed).

**Blinking "E 7"** = water inside the buggy. **Blinking "St"** = the remote's throttle input has
failed (see README); the buggy gets zero throttle.

Try the [glance quiz](https://monterman.github.io/BREmote-V2/followme-screens.html): can you tell
the three apart in a fraction of a second?

### Buzzes (kept to a minimum)

Fewer buzzes means each one gets noticed. Riding cuts how much you feel a buzz, so only the
important events buzz.

| Buzz | Means |
|---|---|
| **two short taps** | armed |
| **one long buzz** + **St** | stopped, refused or a fault |
| **five short** | link to the buggy lost |
| **five long** + **E 7** | water in the buggy |
| **two short**, out of the blue (not after a gesture) | weak signal or low battery |
| **two medium pulses** while holding the magnet | let go now to start the manual return-to-me |

**No buzz** for: distance changes, a station step, or the start of following. Look at the screen
for those.

---

## 7. Stations — where the buggy follows

Stations are **relative to you**, facing your direction of travel:

| Station | Name | Buggy sits |
|---|---|---|
| **F1** | Near-Right | behind and to your right |
| **F2** | Behind (default) | straight behind you |
| **F3** | Near-Left | behind and to your left |
| **F4*** | Front-Right | ahead and to your right |
| **F5*** | Front-Left | ahead and to your left |

**Station tips:** many **regular-stance** riders like **F1 (behind-right)** and **goofy** riders
**F3 (behind-left)**, so the buggy stays on the side you can see without turning your head.

The angle of F1/F3 is `near_diag_offset_deg` off straight-behind (45 = diagonal; bigger = more
beside you, smaller = more behind you). Follow distance is a separate setting (§10).

### Front stations F4 / F5 — \* in development and testing

*\* New in the upcoming release, not yet water-tested. Expect changes.* The buggy firmware supports
them; picking F4/F5 from the remote comes in a later remote update.

Meant for **downwind runs**, where you want the buggy ahead of you instead of behind.

- **Never dead ahead.** Only ahead-left or ahead-right. A buggy on your line would have to speed
  up as you close on it, and a dead motor would stop it in your path.
- **Side margin:** about 13 m (43 ft) to the side of your line, never closer than 35° to straight
  ahead.
- **Extra distance ahead:** your follow distance plus `fm_front_ahead_extra_m` (default 7 m / 23 ft).
- **Protection cone:** the buggy never cuts across your projected path. Once you're above about
  7.5 mph (12 km/h) the cone reaches about 5 seconds ahead of you, up to 30° each side, and gets
  narrower as you go faster (you ride straighter). A 3 m (10 ft) circle protects you when you're
  slow.

---

## 8. Auto-return — summon the parked buggy

*New in the upcoming release.* On by default (`fm_return_mode` = 1, buggy setting).

1. **You stop or fall.** The buggy stops and **parks**. The screen shows **waiting** (one dot
   hopping), the same look as armed.
2. **It waits.** Surf a few waves, swim, pump back. Being busy for a minute or more doesn't cancel
   it.
3. **Squeeze the trigger** when you want it. The buggy turns toward you and comes back. The screen
   switches to **coming to you** (fill-down, metres counting down).
4. **Pause and squeeze again** as often as you like. Let go to see if it's aiming right, squeeze
   gently for a better turn. A release or a pause never cancels the return.
5. **Steering helps, it doesn't cancel**, with `steer_during_auto` = 1 (take over). Push the stick
   to steer it around a wave; centre it and the buggy aims at you again. With the default 0
   (cancel), a held push still ends the return.

**Auto-return ends only by:**

- **arriving** at you: steering is yours at once, throttle **stays capped until one full release**;
- **a fault**: **St** + long buzz, manual control comes back;
- **switching the remote off and on**: the buggy notices and won't resume on its own;
- switching Follow-Me off with the toggle gesture.

**"Waiting" means it will work.** If the buggy itself can't do it (its own GPS, its heading, a
fault) the return ends straight away with **St**. If only the remote's side is briefly missing
(your GPS, a short link drop), the bar blinks in place (not ready); squeeze then and you get St.

If you catch a wave while it's coming back, the return ends. Let go of the trigger fully, squeeze
again, and once the buggy sees you moving away it follows.

---

## 9. Manual return-to-me (RTM)

A separate mode for calling the buggy when Follow-Me isn't armed.

- **Start it with the trigger released:** RIGHT tap, then LEFT hold, or (mag_mode 4) **hold the
  magnet 2.5 s** until two medium pulses, then let go.
- The screen shows **"rn"**. Confirm with the trigger (a squeeze held about 0.5 s, or a double
  squeeze if `rtm_double_squeeze_en` = 1).
- **Changed your mind?** Hold the toggle **LEFT for 1 second** (pushed past half way) during the
  "rn" window: back to full manual at once, **St**.
- If return-to-me can't start (switched off, no GPS) you get **St**.
- Arrival works like auto-return: steering back at once, throttle capped until one full release.

**Gestures need a released trigger.** The return gesture and the 2.5 s magnet hold only start with
the trigger fully released, so steering or nudging a buggy while you hold the trigger never starts
or ends a return by accident. The one exception: a **magnet tap** still arms Follow-Me with the
trigger held.

---

## 10. Holds vs stops

| Situation | What it is | What happens | Re-arm? |
|---|---|---|---|
| You release the trigger | deadman | motor stops | no |
| You fall, slow down or get too close | a **hold** (normal) | buggy stops, stays armed; parks for auto-return if it's on | no |
| GPS, compass or radio drops out | a **fault** | **St** + long buzz, manual control back | yes |

Falling is normal, so it stays ready. A real failure is not, so it steps fully out and waits for
you to arm again. Autonomy never silently restarts after a glitch.

---

## 11. Settings

| Setting | Board | What it does | Default |
|---|---|---|---|
| `fm_display_mode` | remote | what the numbers show while armed: 2 = metres to the buggy | **2** (new) |
| `mag_mode` | remote | magnet role: 0 off, 1 FM, 2 RTM, 3 FM + RTM, **4 tap = FM / station, hold = return-to-me** | 0 |
| `fm_hold_duration_s` | remote | how long the RIGHT hold of the arm gesture is | 3 s |
| `fm_arm_timeout_s` | remote | auto-disarm after this long with no throttle; 0 = never | 0 |
| `fm_warn_distance_m` | remote | distance that fills the bar (full scale) while following. It no longer buzzes. | 150 m |
| `followme_mode` | buggy | station names 1-5 (the remote sends the station) | 2 |
| `near_diag_offset_deg` | buggy | F1/F3 angle off straight-behind | 45 |
| `min_dist_m` | buggy | closest the buggy may get while following; throttle cut inside it | 10 m |
| `followme_smoothing_band_m` | buggy | slow-down band above `min_dist_m`; follow distance = both added | |
| `fm_return_mode` | buggy | auto-return when you stop: 1 on, 0 hold where it is | **1** (new) |
| `steer_during_auto` | buggy | stick during automatic steering: 0 cancel, 1 take over | 0 |
| `fm_front_ahead_extra_m` | buggy | extra metres ahead for F4/F5 (4-10; 0 = 7 m) | 0 |

The [setup wizard](https://monterman.github.io/BREmote-V2/setup-wizard.html) picks these for your
setup and gives you a config to paste. Review it before you ride.

---

## Safety summary (never changes)

1. The buggy moves only while you hold the throttle trigger.
2. Follow-Me and return modes only steer and only reduce throttle. They never add.
3. Releasing the trigger stops the buggy, in every mode.
4. Manual control always works, even if GPS, compass or radio fail.
5. "St" means not working. "Waiting" means it will work.

---

## Credits

- **Ludwig** — BREmote's author: the original remote, the radio code this fork keeps merging from
  upstream, and the battery tools at [lbre.de/BREmote](https://lbre.de/BREmote/).
  Setup video: [youtu.be/r6JIZEq3aTU](https://youtu.be/r6JIZEq3aTU).
  Upstream repo: [github.com/Luddi96/BREmote-V2](https://github.com/Luddi96/BREmote-V2).
- **Heiguga** — Follow-Me ideas, including the front stations.

*See `BUGGY_FOIL_DOMAIN.md` for the domain model and `DESIGN_FOLLOW_ME.md` for the engineering
design.*

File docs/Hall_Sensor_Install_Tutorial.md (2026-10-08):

# Hall Sensor Expansion — Install Tutorial

> **Skill level:** Intermediate soldering required. The DRV5032 SOT-23 package is very small — see hardware alternatives below if you prefer an easier solder job.

This tutorial covers fitting the optional P_MAG Hall sensor. With it, a small magnet touched to the outside of the remote **arms Follow-Me** (even while you're being towed) or **starts Return-to-Me**, without reaching for the toggles. You do not need this sensor — everything also works from the toggles. What each magnet gesture does is in the [Hall Sensor Expansion page](Hall_Sensor_Expansion.md#firmware-behaviour--mag_mode-tx-setting).

> ⚠️ **GPIO 9 is an ESP32-C3 boot (strapping) pin. Never power the remote on with the magnet against it** — it won't boot (dark screen, no buzz). Take the magnet away, power on, then use it.

---

## What You Need

| Item | Notes |
|---|---|
| Hall effect sensor (see options below) | Unipolar, active-low, 3.3V compatible |
| 3× thin wires, ~15–20 cm | 28 AWG or similar — needs to reach from the PCB to the enclosure wall |
| Small neodymium magnet | Disc or cube, 6–10 mm — keep one attached to your wetsuit wrist |
| Heat shrink or liquid electrical tape | Waterproof the sensor leads |
| Soldering iron + fine tip | 0.3–0.5 mm tip recommended for SMD options |
| Multimeter | For continuity test before closing the enclosure |

---

## Hardware Options

### What was used here: TI DRV5032 (SOT-23)

> ⚠️ **The DRV5032 SOT-23 is a very small package** — 3 pads, 1.6 × 2.9 mm footprint, 0.95 mm pitch. If you have never soldered SMD before, use one of the easier options below. The DRV5032 was used because it was already in stock, not because it is the easiest choice.

**DRV5032 SOT-23 specs:**
- Supply: 1.65 V – 5.5 V ✅ (3.3V nominal)
- Output: active-low open-drain
- Current draw: 170 nA (ultra-low — irrelevant here but a nice part)
- Package: SOT-23 (3-pin SMD, very small)

If you source the DRV5032, order a few extras — they are easy to lose and easy to lift a pad on. Use flux, tin the pads first, and work under magnification.

---

### Easier alternatives (same wiring, drop-in compatible)

All options below wire identically: VCC → 3.3V, GND → GND, OUT → GPIO 9.

| Part | Package | Why it's easier | 3.3V? | Notes |
|---|---|---|---|---|
| **US5881LUA** | SIP-3 (TO-92 style) | Through-hole leads, easy hand solder | ✅ 2.5V min | Widely available, cheap, reliable |
| **OH090U** | SIP-3 (TO-92 style) | Through-hole leads, easy hand solder | ✅ 2.7V min | Omnipolar — works with either magnet pole |
| **AH1806** | SOT-23 | Same size as DRV5032 but more available | ✅ 1.65V min | No easier to solder, but easier to source |
| **DRV5032** larger pkg | WSON-6 or SOT-23W (if available) | Slightly larger pads | ✅ | Check your distributor for package variants |

**Recommended for most builders: US5881LUA or OH090U** — through-hole leads make placement and soldering straightforward, no SMD skills required.

> **Magnet polarity note:** The DRV5032 and US5881 are unipolar — they activate on the **south pole** of the magnet facing the sensor. If your magnet doesn't trigger it, flip it over. The OH090U is omnipolar and works with either pole.

---

## Wiring Diagram

Connect the sensor to the HT-CT62 board as shown:

HT-CT62 Hall Sensor Wiring

*[SVG version for printing](HT-CT62%20Hall%20Sensor%20Wiring.svg)*

```
Sensor VCC  → 3.3V rail on HT-CT62
Sensor GND  → GND
Sensor OUT  → GPIO 9 (P_MAG)
```

The firmware uses the internal pull-up on GPIO 9 — no external resistor needed. Output is active-low: pulls to GND when a magnet is near, floats high otherwise.

---

## Step-by-Step Installation

### Step 1 — Prepare the sensor leads

Cut three lengths of 28 AWG wire, ~15–20 cm each (adjust to fit your enclosure routing). Strip 2 mm at each end.

For **SIP-3 parts (US5881, OH090U):** bend the leads gently at 90° so the sensor body sits flat against the enclosure wall. Pre-tin the leads before inserting.

For **SOT-23 parts (DRV5032, AH1806):** solder the three wires to the pads on a breakout board or directly to the IC. Apply flux first. Tin each pad, then tin each wire, then join — do not apply heat for more than 2–3 seconds per pad.

### Step 2 — Route wires inside the enclosure

Plan the route from the sensor mounting point (inside enclosure wall, near where you will hold the magnet) to the HT-CT62 board. Leave a small service loop so you can open the enclosure later without straining the joints.

Secure the wires with a small amount of hot glue or a cable tie — avoid routing directly over any RF antenna trace on the HT-CT62.

### Step 3 — Solder to the HT-CT62

Identify the following points on the HT-CT62 board:

| Signal | Where to solder |
|---|---|
| 3.3V | 3V3 pad or existing 3.3V component |
| GND | GND pad |
| GPIO 9 | GPIO 9 pad (P_MAG) — check the board silkscreen or pinout diagram |

Solder with a fine tip. GPIO 9 is a small pad — use flux and keep the iron on it no longer than 2 seconds.

### Step 4 — Mount the sensor

Position the sensor flat against the inside of the enclosure wall at a spot you can reach with the magnet from outside while riding. The sensor face must be within ~5 mm of the enclosure wall for reliable activation — most 3D-printed or thin ABS walls work fine.

Apply a small blob of hot glue to hold it in place. Let it cure before closing the enclosure.

Waterproof the three solder joints and exposed leads with heat shrink or liquid electrical tape. This is a water-adjacent device.

### Step 5 — Continuity test

Before closing the enclosure:

1. Power on the TX (on battery — not USB)
2. Hold your test magnet against the sensor face
3. Check with a multimeter that GPIO 9 reads near 0 V with magnet present, ~3.3 V without
4. If inverted, flip the magnet — you have the wrong pole facing the sensor (unless you used an OH090U, which is omnipolar)

### Step 6 — Configure the magnet role

Connect to the TX via the Web Serial Config Tool or serial at 115200 baud and pick a `mag_mode`:

```
?set mag_mode 4
?save
```

- **`mag_mode 4`** *(new in the upcoming release; nightly builds on the [`fm-stations` branch](https://github.com/monterman/BREmote-V2/tree/fm-stations))*: a **tap** arms Follow-Me or steps the station; a **2.5 s hold with the trigger released** starts the manual Return-to-Me.
- **`mag_mode 1-3`** *(current master firmware)*: hold about 2 s for Follow-Me (modes 1 and 3), about 5 s for Return-to-Me (mode 3); the action happens when you take the magnet away. Mode 2 uses the 2 s hold for Return-to-Me.
- **`mag_mode 0`** with `bt_enabled 1`: the older role — the magnet switches BLE on for the session (BT dot at C7 R1 slow-blinks; hold 5 s more for fast blink, then VESC Tool can connect).

**Test it:** power the TX on battery **with the magnet away**. With `mag_mode 4`, tap the magnet once: two short taps and the waiting screen = Follow-Me armed. Switch it off again with the toggle gesture.

---

## Magnet Tip

A small disc neodymium magnet (6–8 mm diameter, N35 grade) is ideal. Stick it to the inside of a wetsuit wrist strap or glove cuff — you can arm Follow-Me by touching your wrist to the remote without taking your hand off the throttle. Keep it away from the remote when you switch it on.

---

## Troubleshooting

| Symptom | Check |
|---|---|
| Remote won't boot (dark, no buzz) | The magnet was near the sensor at power-on (GPIO 9 is a boot pin). Remove it and power on again. |
| Magnet tap does nothing | `mag_mode` set and saved? Follow-Me enabled and GPS on? After a station step, taps for 1 s are ignored. |
| Magnet hold does nothing | The 2.5 s hold (mode 4) only works with the trigger fully released. |
| BT dot never blinks | Only in `mag_mode 0`: `bt_enabled = 1` set and saved? Boot on battery (not USB)? |
| Magnet held but no response | Magnet polarity — try flipping it. Sensor within 5 mm of wall? |
| BT dot blinks constantly without magnet | GPIO 9 floating — check the OUT wire is soldered securely |
| VESC Tool can't find device | BT dot must be fast-blinking, not slow. Hold magnet 5 s past slow blink. |
| No USB boot fix | USB-C power triggers charger mode — always boot on battery for BLE |

---

## Related

- [Hall Sensor Expansion — reference page](Hall_Sensor_Expansion.md)
- [BLE Implementation — protocol details](BLE_Implementation.md)

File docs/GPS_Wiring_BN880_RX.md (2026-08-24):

# BN-880 → RX Wiring (GPS + Compass)

**Applies to:** V2.5-Evo RX (HT-CT62 / ESP32-C3) with a **BN-880** GPS module.
**Why the BN-880:** it carries a **QMC5883L magnetometer**. The RX needs a compass for
**Return-to-Me** and **Follow-Me** heading — a BN-220 has no compass and cannot run those modes.

> This covers the **module-to-board** wiring only. Waterproof connectors and pack wiring are
> deliberately not covered — everyone uses different connectors, so pick your own and keep the
> signal mapping below.

---

## Pin map — the six wires

The RX board's pads are labelled on the silkscreen — **wire label to label**. The GPIO numbers below
are only for reference when you need them; they are not what you wire to.

Four wires go to the **`UART 1.1` header** (the right-hand one — see below). The other two, `SDA` and
`SCL`, go to bare pads on the **underside** of the board.

| BN-880 pad | RX board pad | GPIO behind it | Notes |
|---|---|---|---|
| **VCC** | `V+` on `UART 1.1` | — | **5 V** — put that header's selector on `5V`, not `3V3` |
| **GND** | `GD` on `UART 1.1` | — | Common ground with the RX |
| **TX** | **`TX`** on `UART 1.1` | 19 | **straight** — label to label |
| **RX** | **`RX`** on `UART 1.1` | 18 | **straight** — label to label |
| **SCL** | `SCL` pad — **underside** | 1 | straight |
| **SDA** | `SDA` pad — **underside** | 2 | straight |

> **The `SDA` and `SCL` pads are on the BOTTOM of the board**, just north of the ESP32-C3 module —
> two bare round pads sitting immediately above its antenna castellations, under the
> `(c) Ludwig Bre` silkscreen. They are labelled `SDA` and `SCL` on the bottom silkscreen. Flip the
> board over to find them; there is nothing to see on the top side.

## Nothing crosses. Wire label to label.

`TX`→`TX`, `RX`→`RX`, `SCL`→`SCL`, `SDA`→`SDA`. **The board already does the crossover for you.**

This is the opposite of the usual serial convention, so it is worth knowing *why*, and the board
files prove it rather than asserting it. Tracing the `UART 1.1` header back through the mux to the
ESP32-C3 in `Rx_V2-2.sch`:

```
pad `RX` (JP9.2) ── Q2 ── U1_1_RX ── IC6 mux 1Y1→1Z ── HT-CT62 pin G18   = GPIO 18
pad `TX` (JP9.3) ── Q5 ── U1_1_TX ── IC6 mux 2Y1→2Z ── HT-CT62 pin G19   = GPIO 19
```

and the firmware opens the port as:

```c
Serial1.begin(baud, SERIAL_8N1, P_U1_RX, P_U1_TX);   // GPS.ino
#define P_U1_TX 18                                   // BREmote_V2_Rx.h
#define P_U1_RX 19
```

So the ESP32 **transmits on GPIO 18 and receives on GPIO 19** — which means the pad silkscreened
**`RX` is driven by the board's transmitter**, and the pad silkscreened **`TX` is the board's
receiver input**.

The silkscreen is therefore naming **what you connect there**, not the signal the pin carries. Pad
`RX` wants the module's `RX`. That is why Ludwig's original diagrams show a direct connection: the
crossover is designed into the PCB, so doing it again in the cable un-does it.

> **A naming trap, if you ever read the schematic yourself.** The schematic net called `P_U1_RX`
> lands on GPIO 18, while the firmware's `#define P_U1_RX` is 19 — the same name means opposite
> things in the two files, because the schematic names nets from the *peripheral's* point of view.
> The physical trace above is what settles it.

### Which header — `UART 1.1`, the right-hand one

The board has **two UART headers**. They are *not* two independent serial ports: they are one
hardware UART (`Serial1`) shared between two connectors by a 74HC4052 analog mux, which the firmware
flips back and forth. That is what the `.0` and `.1` in the silkscreen mean — **UART1, mux channel 0
and mux channel 1**.

```
   UART 1.0                UART 1.1
    5V   3V3                5V   3V3      <- supply selector (GPS: 5V)
   V+  RX  TX  GD          V+  RX  TX  GD
   └──── VESC ────┘        └──── GPS ─────┘
```

| Header | Mux channel | Peripheral |
|---|---|---|
| `UART 1.0` | 0 | **VESC** |
| `UART 1.1` | 1 | **GPS** — wire the BN-880 here |

Straight from the firmware (`Source/V2_Integration_Rx/System.ino`, `setUartMux()`):

```
//   channel 0 (VESC): MUX_0 = LOW,  MUX_1 = LOW
//   channel 1 (GPS):  MUX_0 = HIGH, MUX_1 = LOW
```

The board files agree. In `Electronics/github_public/Rx/Rx/Rx_V2-2.sch` the two 1×4 headers carry
nets named `UART_1_0_RX` / `UART_1_0_TX` (header `JP5`) and `UART1_1_RX` / `UART1_1_TX` (header
`JP9`) — the silkscreen is naming the net, and the net is naming the mux channel.

Each header's supply selector is a **3-pin jumper** (`JP7` for `1.0`, `JP10` for `1.1`): the middle
pin feeds that header's `V+` pad, and you bridge it to one side or the other. For the BN-880,
bridge it to the **5 V** side.

⚠️ **Wire the GPS into `UART 1.0` and it will never work** — that connector is on the VESC channel,
so the module's bytes are switched away from the UART. The symptom is identical to a TX/RX swap:
nothing at any baud from `?gpsbaud`. Confirm you are on the **right-hand header** before you start
swapping data wires.

### Power the BN-880 from 5 V — not 3.3 V

Each UART header has its own **`5V` / `3V3`** selector. On `UART 1.1` it goes on **`5V`**.

The BN-880 is a 5 V module: it has an onboard regulator that drops 5 V to the 3.3 V its u-blox core
and QMC5883L need. Run it from the 3.3 V rail instead and you sit right on the regulator's dropout —
which does not fail cleanly. You get a module that boots, enumerates, sometimes even reports sats,
then browns out under the current draw of an acquisition burst. That reads as flaky GPS, not as a
power problem, and it will waste a day.

The reference build takes **5 V off the VESC's 5 V output**. That is the known-good arrangement.

**The data lines are still 3.3 V logic**, even with a 5 V supply — the module's UART TX and its I2C
lines run at the internal 3.3 V rail. No level shifter is needed between the BN-880 and the
ESP32-C3, and nothing on the board sees 5 V on a signal pin.

> The `3V3` position on the selector exists for modules that want 3.3 V — the HGLRC M100 series,
> for example, accepts 3.3–5 V. It is not the right setting for a BN-880.

> ### Bench-check it before you seal anything up
>
> Straight is what the board files, the firmware and Ludwig's own diagrams all say — but confirm it
> on your unit before it goes anywhere near water. Board revisions vary, and this costs two minutes:
>
> 1. Wire it **straight** on the **`UART 1.1`** header — `TX`→`TX`, `RX`→`RX`.
> 2. Power up and run **`?gpsbaud`** — a listen-only baud scan that reports whether *any* bytes are
>    arriving. No sky and no fix needed, so it answers the wiring question on its own.
> 3. **Bytes at some baud → correct.** Confirm outdoors with `?printgps` for sats and a position.
> 4. **Nothing at any baud →** swap just the two data wires and run `?gpsbaud` again. Swapping UART
>    data lines cannot damage anything — both ends are 3.3 V logic — so this is a free test.
> 5. Whichever way returns bytes is correct for your board. If it turns out to be the swapped one,
>    please open an issue saying so; that would mean a revision differs from the files.
>
> The same applies to the VESC on `UART 1.0` — probe that one with `?vescraw`, then `?vescping`.

```
        BN-880 module                    RX board — UART 1.1 header (GPS)
   ┌──────────────────────┐                 ┌──────────────────────────────┐
   │                      │                 │                              │
   │  VCC  ───────────────┼─── red ────────►│  V+    selector on 5V        │
   │  GND  ───────────────┼─── black ──────►│  GD                          │
   │                      │                 │                              │
   │  TX   ───────────────┼─── straight ───►│  TX    (GPIO 19)      UART   │
   │  RX   ◄──────────────┼─── straight ────┤  RX    (GPIO 18)      UART   │
   │                      │                 │                              │
   │  SCL  ───────────────┼─── straight ───►│  SCL   pad, underside        │
   │  SDA  ───────────────┼─── straight ───►│  SDA   pad, underside        │
   │                      │                 │                              │
   └──────────────────────┘                 └──────────────────────────────┘
       GPS + QMC5883L                         compass answers at 0x0D

        SDA and SCL are bare pads on the BOTTOM of the board, north of
        the ESP32-C3 — not on the UART header. Flip it over.

              every wire goes label to label — nothing crosses
             (the board does the UART crossover internally)
```

Wire colours vary between vendors — **go by the silkscreen labels on the module**, not by colour.

### Where the `SDA` / `SCL` pads are — on the underside

**Flip the board over.** They are two bare round pads on the **bottom** side, just **north of the
ESP32-C3 module** — immediately above its 2.4 GHz antenna castellations, directly under the
`(c) Ludwig Bre 03/2025` silkscreen. Both are labelled on the bottom silkscreen.

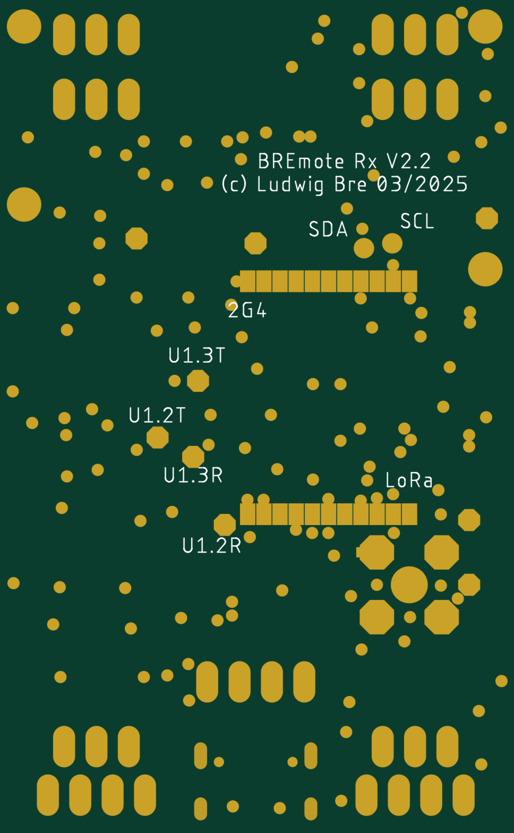
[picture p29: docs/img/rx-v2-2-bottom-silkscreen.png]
RX V2.2 bottom silkscreen — SDA and SCL pads above the 2G4 castellations


*Bottom silkscreen and soldermask, rendered from `Rx_V2-2_Gerber.zip` and mirrored so it reads the
way it does with the board flipped over in your hand.*

```
                 bottom side, as you look at it
        ┌───────────────────────────────────────────┐
        │        BREmote Rx V2.2                    │
        │        (c) Ludwig Bre 03/2025             │
        │                                           │
        │            SDA ●     ● SCL                │  <- the two pads
        │        ▄▄▄▄▄▄▄▄▄▄▄▄▄▄▄▄▄▄▄▄▄              │
        │            2G4  (antenna castellations)   │
        │                                           │
        │        U1.3T ●   U1.2T ●                  │  <- spare UART pads
        │        U1.3R ●   U1.2R ●                  │     (mux ch 2 and 3)
        └───────────────────────────────────────────┘
```

| Pad | Diameter | Position from the board's top-left corner |
|---|---|---|
| `SDA` | 1.6 mm | 11.5 mm in, 19.3 mm down |
| `SCL` | 1.6 mm | 9.3 mm in, 18.9 mm down |

They are 2.2 mm apart, so use a fine tip. **Nothing is exposed on the top side** — do not go looking
for them there.

**Why they are not in the schematic.** They are bare pads dropped onto an existing signal in the
*layout*, not a component, so no device appears on the `.sch` sheet — tracing nets there finds only
the AW9523 expander, the pull-ups and the module, and no connector. Ludwig's own changelog records
when they were added:

```
Changelog Rx
V2.2:
- Change supply for CH340K to before USB diode
- Add SDA and SCL pads
```

So **a V2.1 board does not have them and a V2.2 does.** Check which revision you have — it is printed
on the bottom silkscreen. Positions above were read from `Rx_V2-2_Gerber.zip` (bottom silkscreen and
soldermask layers), which is the authority for anything that exists only in the layout.

---

## After wiring — three things, in this order

### 1. Tell the firmware which module you fitted
The RX must be told it has a BN-880, or it will not configure the module correctly:

```
?set gps_chip_type 1        # 0 = BN-220, 1 = BN-880, 2/3 = M10
?save
```
Reboot after saving.

### 2. Check the build setting that shares these pins
The ESP32-C3 USB peripheral claims **GPIO 18/19** — the same pins the GPS uses. If you compile it
yourself, **USB CDC On Boot must be Disabled** (`Tools → USB CDC On Boot → Disabled`, or
`:CDCOnBoot=default` on the arduino-cli FQBN). The firmware refuses to build otherwise. Prebuilt
`.bin` files are already correct.

### 3. Verify before you trust it
```
?gpsbaud      # listen-only: are any bytes arriving at all? (answers the wiring question)
?printgps     # sats, fix and position = the link is working end to end
?magtest      # EMI test + verdict - BUCKET/DOCK, motor MUST be loaded (see Mounting)
?compasscal   # full calibration — rotate the buggy through a complete horizontal circle
```
No bytes at any baud is a **UART orientation** problem — swap the two data wires and retest (see the
note above). Compass not found at `0x0D` is almost always **SDA/SCL swapped** or a bad ground.

---

## Mounting — this matters more than people expect

The magnetometer sits in the same module as the GPS, and **motor phase wires and battery leads
throw the heading off by 100°+ at throttle**. On the RX a bad heading is a Follow-Me fault, not a
cosmetic problem.

- Mount the BN-880 **square to the buggy** — its own forward axis lined up with the nose, or turned
  exactly 90°, 180° or 270° from it. **Not diagonal.** The firmware stores the mounting rotation only
  as one of those four values, so a module at, say, 30° gets stored as 0° and keeps 30° of heading
  error that no calibration can remove.
- Mount the BN-880 **as far from the battery and phase wires as the build allows**. Two inches
  makes a large difference at close range.
- **Never mount it over a loop or U-turn in the phase wires.** This is the single worst position
  and it is easy to create by accident. Out-and-back conductors cancel each other's field *at a
  distance*, but at the centre of the loop they **add** — a current loop behaves like a magnet, and
  its field there is far stronger than a straight wire at the same spacing. If the module sits
  above where the phase wires turn back on themselves, fix that before anything else.
- **Twist the phase wires into a tight bundle.** Paired conductors cancel, and the leftover field
  then falls away much faster with distance than a single wire's does. This can buy more than
  moving the module.
- Keep it away from ferrous hardware and anything carrying high current.
- Run `?magtest` **in place, on the real build, WITH THE MOTOR UNDER LOAD** — prop in a bucket of
  water or held against the dock. ⚠️ **Never judge it free-spinning.** The same buggy measured
  +3-5° free-spinning and **87-101° under load** — seven times worse. A free-spinning prop draws
  almost no current and reads clean on a compass that is useless in the water. `?magtest` now
  refuses to grade a run whose peak current stayed under 5 A, and prints a verdict at the end.
- **Re-run `?compasscal` after any change** to module, position, or mounting. A stored calibration
  does not carry over: different module, different mounting, different hard/soft-iron offsets.

---

## Moving the module out on a cable — and shielding it

Relocating the BN-880 away from the electronics is the single most effective fix for compass EMI,
because **distance is the only thing that works.** A magnetometer cannot be shielded from a
magnetic field in any practical way — copper, aluminium and steel foil all pass it straight
through at these frequencies. If the module is near the phase wires, it is wrong, and no amount of
wrapping changes that.

What shielding *does* fix is a different problem: **electrical noise picked up by the cable.**

### Two problems, two fixes — do not confuse them

| Problem | What it does | Fix |
|---|---|---|
| **Magnetic field reaching the sensor** | Heading off by up to 100° under throttle | **Distance only.** Move the module. |
| **Electrical noise reaching the wires** | Corrupted I²C/serial data, dropped compass reads, GPS glitches | **Shielding.** Copper tape or a shielded cable. |

Moving the module onto a cable solves the first and *creates* the second — the cable now runs
past the ESC and the battery leads, acting as an antenna. That is why you do both.

### ⚠️ Never wrap the module itself

**Shield the CABLE, never the GPS module or its antenna patch.** The GPS antenna has to see the
sky. Wrapping the module in copper tape will cost you satellite lock entirely. This mistake is
easy to make because "shield the GPS" sounds like it means the whole thing.

### How to shield the cable

This is standard practice in the FPV/drone world, where the same problem exists in a smaller box.

1. **Use copper tape, not aluminium.** Copper tape is sold with *conductive adhesive*, so the
   overlapping seams conduct and the shield behaves as one surface. Aluminium tape usually has
   insulating adhesive, which leaves every seam as a gap.
2. **Twist the signal pairs first**, then wrap. Twisting is what rejects magnetic pickup; the
   shield handles the electric field. Twisting also matters for I²C length — see the cable-length
   limits below.
3. **Wrap the full run**, overlapping each turn by about half its width. The noisiest stretch is
   the first few inches next to the ESC, so do not leave that bare.
4. **Ground the shield at ONE END ONLY — the RX end.** Grounding both ends creates a loop between
   the two ground points, and a loop is exactly what you are trying to get away from. One end
   drains the noise; two ends invite current to flow through the shield.
5. **Insulate the outside** with heatshrink or tape. Bare copper against a battery terminal or a
   connector shell is a short waiting to happen.

### Cable length limits — this catches people out

The GPS runs on a serial line and will happily go a metre. **The compass runs on I²C, which will
not.** I²C can only pull the line down; it relies on a passive resistor to pull it back up, and a
longer cable takes longer to charge. Too long and the receiver samples the bit before it arrives.

**Shielding makes this worse, not better** — the shield is a conductor right next to the signal
wires, so a shielded cable has roughly double the capacitance of loose wire per unit length.

| I²C bus speed | Practical maximum cable |
|---|---|
| **400 kHz** | **~12 in / 30 cm** — and that is with shielded cable, at the edge |
| **100 kHz** | **~3 ft / 1 m** comfortably |

If you are running longer than about 12 inches, drop the bus to 100 kHz (`Wire.setClock` in
`Init.ino`). Nothing on that bus needs the speed — a compass read goes from ~150 µs to ~600 µs,
invisible at the 10 Hz the firmware polls at.

Symptoms of an over-long I²C run are easy to misread as a dead module: `?i2c` finding the compass
only sometimes, occasional garbage readings, calibrations failing for no visible reason.

### Where to put it

Out in front, away from the ESC, the battery leads and the motors — and **never over a loop or
U-turn in the phase wires.** Out-and-back conductors cancel each other at a distance, but at the
centre of the loop they *add*, and the bundle behaves like a magnet rather than like two wires.
A module sitting over the point where the phase wires turn back on themselves is in the worst
possible place, and it is easy to create by accident. Holland Shielding's drone EMI guidance makes
the same point: keep the compass out of the surface of a current loop.

Then run `?magtest` **under load** and confirm the number.

### References

Same problem, same fixes, from the drone world:

- [GPS Placement — ARK Electronics](https://docs.arkelectron.com/knowledge-base/knowledge-base/gps-placement)
- [EMI for Drones — Holland Shielding Systems](https://hollandshielding.com/en/emi-for-drones) — current loops and compass placement
- [Install copper foil shield (fix low satellite count) — PhantomPilots](https://phantompilots.com/threads/how-to-install-copper-foil-shield-fix-low-satellite-count.31054/)
- [GPS Shielding (wires?) — IntoFPV](https://intofpv.com/t-gps-shielding-wires)
- Video: [GPS Cable Shielding](https://www.youtube.com/watch?v=3vD6K-KfmBA)
- Video: [Why Does Shielding GPS Wires Matter? Aren't They Digital?](https://www.youtube.com/watch?v=RkLIJB1lOhc)
- Video: [Copper Tape Install and GPS Test](https://www.youtube.com/watch?v=EC0HSKuWmvk)

---

## Related

- [GPS configuration, baud rates and dynamic model →](GPS.md)
- [GPS troubleshooting →](hardware/gps-troubleshooting.md)
- [Follow-Me guide →](FOLLOW_ME_GUIDE.md)
- [RX flashing guide →](FLASHING_RX_ARDUINO.md)

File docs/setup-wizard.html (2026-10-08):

nightly firmware. These docs, the setup wizard and the new screens match the nightly firmware on the fm-stations branch (https://github.com/monterman/BREmote-V2/tree/fm-stations), not the firmware on master. Nightly = bleeding edge, under water testing, use at your own risk. Binaries are in the latest-FM-stations folders.

# BREmote V2.5-Evo — Setup Wizard

Prototype. Answer the questions, get a config for the remote and a config for the buggy. About 8 minutes.

Only for BREmote V2.5-Evo firmware (the fm-stations nightly: buggy SW 36 and remote SW 27 from that branch; older SW 36/27 builds and master lack some of these settings). The settings this wizard writes do not exist in Ludwig's stock BREmote firmware: do not use it with stock firmware, or with older V2.5-Evo builds. Check the version your board prints at boot (?conf shows "version") before pasting anything.

Browse mode is on: flip to any page with the chips or Back/Next, no answers needed. Unanswered questions use the recommended choice, so the Results page always shows a full example config. Turn Browse mode off to answer the questions for your own setup. New in the upcoming release: in the nightly builds on the fm-stations branch (https://github.com/monterman/BREmote-V2/tree/fm-stations) now; it moves to master gradually after more water testing.

Browse mode

Back

Next

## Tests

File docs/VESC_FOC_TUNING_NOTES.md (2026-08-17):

# VESC FOC Tuning Notes — Smooth Start for E-Foil Underwater Operation

Date: 2026-05-03
Scope: Analysis of Andres's existing VESC motor config (`new FOC 6384 vesc1`), recommendations to fix the "needs ~35–40% throttle to start spinning underwater" symptom, and a brief on FOC vs BLDC for this application. Read-only analysis. No firmware or VESC config files were modified.

---

## EXECUTIVE SUMMARY

1. **Your symptom is a classic FOC sensorless startup-torque problem, not a BREmote bug.** The motor doesn't break free from underwater static load until throttle gets high enough to push real current through. The fix is in VESC, not in the remote.

2. **Three VESC parameters do 80% of the work.** `foc_sl_openloop_boost_q` (currently `0`), `foc_openloop_rpm` (currently `1500`), and `cc_startup_boost_duty` (currently `0.01`). Tune these and the motor will spin at 10–15% trigger reliably.

3. **FOC is the right choice for your use case.** Confirmed via web research and your config: quieter, smoother at low speed, more torque at startup *when properly tuned*. BLDC is louder, has audible cogging, and has worse low-speed control — bad fit for underwater silent operation.

4. **BREmote can help slightly via `thr_expo`** but only as a curve-shaping tool, not a torque-boost. With `thr_expo = 50` (true linear, your planned change) the curve doesn't fight VESC's startup tuning. **Don't use BREmote as a startup booster** — it would either be a Section 9 safety violation (autonomous throttle add) or duplicate work the VESC should do.

5. **Hardware path forward (future, not now):** add hall sensors or an encoder to your motor. Sensored FOC has full torque from zero RPM with known rotor position — completely eliminates the startup hesitation. Sensorless FOC is always a guess at low ERPM. This is the ultimate fix but requires motor mods.

---

## 1. FOC vs BLDC — confirmed for your use case

### Quick verdict for e-foil
**FOC.** Sources from VESC project forum and motor-control documentation back you up on every claim:

- **Quieter** — confirmed. FOC produces sinusoidal phase currents; BLDC produces trapezoidal commutation pulses with audible switching. Underwater the difference is even more pronounced because hull/water transmits high-frequency switching noise.
- **Smoother at low speed** — confirmed. FOC was originally designed for full-torque operation across the entire speed range, including zero. BLDC has ripple torque from its 6-step commutation that becomes audible/feel-able cogging at low RPM.
- **More precise** — confirmed. FOC uses continuous Park/Clarke transforms to control D and Q axis currents independently. BLDC just switches phases on/off based on rotor position estimate.
- **Harder to configure** — confirmed. FOC requires accurate motor parameter measurement (`R`, `L`, `flux linkage`) and observer tuning. BLDC mostly works with default parameters once polarity is right.
- **More power/torque** — partially true. FOC delivers more *usable* torque in low-speed regions. At high RPM the difference shrinks. For e-foil where you spend a lot of time at moderate RPM, FOC has a clear advantage.

### Caveat — FOC sensorless at very low speed is genuinely tricky
FOC sensorless uses back-EMF to estimate rotor position. Below a critical ERPM there's not enough back-EMF to estimate accurately, so VESC runs in **open-loop** mode: it just forces a rotating magnetic field at a programmed rate and hopes the rotor follows. If the load is too high (water on a static prop), the rotor doesn't follow, the openloop current does no useful work, and you feel "the motor doesn't start until I push the trigger."

This is exactly your symptom. It's not a defect — it's how sensorless FOC works. The fix is to either:
- Give openloop more current/torque to break free of the static load, OR
- Reduce the openloop window (lower the threshold at which sensorless takes over).

Both knobs are in VESC config. See §3.

---

## 2. Your current VESC motor config — what I found

Source file: `<VESC config folder>/new FOC 6384 vesc1` (XML format, parsed line-by-line).

### Power and current limits — these look reasonable
| Parameter | Your value | Comment |
|---|---|---|
| `motor_type` | 2 (FOC) | ✅ Correct |
| `foc_sensor_mode` | 0 (Sensorless) | ⚠ See §4 about adding sensors |
| `l_current_max` | 95 A | Generous for a 6384, fine |
| `l_current_min` | -60 A | Brake/regen current — fine |
| `l_in_current_max` | 100 A | Battery side, fine |
| `l_abs_current_max` | 250 A | Fault limit, leave alone |
| `l_min_duty` | 0.005 | Very low (0.5%) — fine, don't raise |
| `l_max_duty` | 0.96 | Standard, leave alone |
| `l_min_vin` | 23 V | 6S min — confirm against your battery |
| `l_max_vin` | 72 V | 16S max — confirm against your battery |
| `motor_poles` | 14 (=7 pole pairs) | ✅ Correct for 6384 outrunner |

### Detected motor parameters — auto-measured, look good
| Parameter | Your value | Comment |
|---|---|---|
| `foc_motor_r` | 0.0233 Ω | Reasonable for 6384 |
| `foc_motor_l` | 18.4 µH | Reasonable for 6384 |
| `foc_motor_flux_linkage` | 0.00493 Vs/rad | Reasonable for 6384 |
| `foc_observer_gain` | 41.2 M | Auto-calculated from R/L/λ — leave alone |

### **The startup-tuning parameters — these are your knobs**
| Parameter | Your value | Recommended | Why |
|---|---|---|---|
| **`foc_sl_openloop_boost_q`** | **0** A | **3–8 A** ⭐ | Extra Q-axis (torque-producing) current during open-loop startup. Currently zero, which is why the motor won't move under water load. **This is your #1 lever.** |
| **`foc_openloop_rpm`** | **1500** | **800–1200** | Below this ERPM the motor is in open-loop mode (forced rotation, no feedback). Lowering it means VESC switches to closed-loop sensorless sooner — which has better torque control. |
| `foc_openloop_rpm_low` | 0 | 0 (leave) | Lower threshold for ramp-down. Keep at 0. |
| `foc_sl_openloop_hyst` | 0.1 | 0.1 (leave) | Hysteresis around the openloop transition. Default OK. |
| `foc_sl_openloop_time_lock` | 0 | 0–0.05 s | Time to "lock" rotor at zero before starting rotation. 0.05s can help motors that need to align. Try 0 first. |
| `foc_sl_openloop_time_ramp` | 0.1 s | 0.1 s (leave) | Time to ramp from zero to openloop_rpm. Leave alone. |
| `foc_sl_openloop_time` | 0.05 s | 0.05 s (leave) | Time at openloop_rpm before transitioning. Leave alone. |
| `foc_sl_erpm_start` | 2500 | 1500–2000 | ERPM at which sensorless transition begins. |
| `foc_sl_erpm` | 3400 | 2500–3000 | ERPM at which sensorless is fully active. |
| `foc_start_curr_dec` | 1 | 1 (leave) | Current decay factor at startup. Default OK. |
| `foc_start_curr_dec_rpm` | 2500 | 2500 (leave) | RPM where current decay completes. |
| `cc_startup_boost_duty` | 0.01 | 0.01–0.05 | Min duty cycle at startup. Could raise slightly. Lower priority than openloop_boost_q. |

### Why your motor needs ~35–40% throttle to start
At 35% throttle, VESC commands roughly 33A motor current (35% × 95A max). At openloop, that 33A is enough to overcome water resistance + rotor inertia and the rotor follows the forced field. Below ~33A, the openloop current isn't producing enough torque to spin the loaded prop — you're commanding rotation but the rotor stays put.

With `foc_sl_openloop_boost_q = 5A`, VESC adds 5A on top of whatever the throttle commands during openloop. Your 10–15% throttle commands ~10–14A; with the boost it's ~15–19A — enough to break free in most underwater conditions. Once the prop is spinning and ERPM > `foc_openloop_rpm`, sensorless kicks in and your 10–15% throttle goes to producing actual motor torque, no boost needed.

---

## 3. Recommended VESC config changes — in priority order

### Step 1 — increase openloop Q boost (biggest single win)
In VESC Tool → Motor Settings → FOC → Advanced → Sensorless tab:
- Set `Open-Loop Boost (Q)` from `0` to `3` initially.
- Test on bench (no prop, motor in air): should spin at ~10% trigger, smooth.
- Test in tub of water with prop submerged: should spin at ~15–20% trigger.
- If still hesitant, raise to `5`. If smooth at 5 but you want even quicker break-free, raise to `8`.
- **Hard cap: 10 A.** Above this you risk overcurrent fault on the battery side and excessive heat in the motor when stalled at low RPM.

### Step 2 — lower openloop RPM threshold
In the same tab:
- Set `Sensorless Open-Loop RPM` (`foc_openloop_rpm`) from `1500` to `1000`.
- This makes VESC trust its observer earlier. With your motor's R/L values, the observer should be reliable down to ~800 ERPM.
- If you start getting fault 6 (`UNDERVOLTAGE` from observer disagreement) or rough running at low speed, raise back toward 1500 in steps of 100.

### Step 3 — lower sensorless transition ERPM
- Set `Sensorless ERPM Start` from `2500` to `1500`.
- Set `Sensorless ERPM` (full sensorless) from `3400` to `2500`.
- These define the band where VESC blends openloop and sensorless modes. Lower transition = faster handoff = smoother low-speed.

### Step 4 — verify input config for full BREmote range
This is independent but mandatory after the smooth-start tuning. The app config file you tried to upload (`app vesc1 bremote v1 (1)`) appears empty or unreadable on my end — I couldn't parse it. **Re-export from VESC Tool** as XML and drop it in the same folder; I'll review the PPM input mapping next session.

When you do re-run PPM Mapping, follow the §3.4 procedure from `THROTTLE_PIPELINE_ANALYSIS.md`:
- BREmote `throttle_mode = 1` (no gears)
- BREmote `thr_expo = 50` (true linear — your planned change)
- RTM disarmed, system unlocked
- Trigger to physical max → save max
- Trigger to physical min → save min

### Step 5 — order of operations on first calibration
1. Set `foc_sl_openloop_boost_q = 3` first.
2. Run motor detection (FOC wizard) to confirm motor parameters didn't drift.
3. Run input PPM Mapping with BREmote at full range.
4. Bench test the motor with no prop — confirm smooth start at <15% trigger.
5. In-water test with prop submerged but board out of water (or in a tub) — confirm break-free at ~15–20% trigger.
6. If too eager (motor wants to start before you're ready), lower boost to 2. If still sluggish, raise to 5.
7. Then make your other tweaks (`foc_openloop_rpm`, `foc_sl_erpm*`) one at a time, test between each.

---

## 4. The hardware fix (future, not now)

Sensored FOC eliminates the openloop guesswork entirely. With hall sensors or an absolute encoder, VESC always knows rotor position, even at zero RPM. Result: full torque from zero, no hesitation, no openloop boost needed.

For e-foil, hall sensors are the practical option. Optical encoders don't survive water. Hall sensors are sealed in the motor stator slots and are common on hoverboard-class motors — your 6384 may or may not have them depending on vendor.

If your 6384 has hall sensors:
- Wire them to VESC's sensor connector (5V, GND, H1, H2, H3).
- In VESC: `foc_sensor_mode` = 1 (Hall) instead of 0 (Sensorless).
- Re-run motor detection; VESC measures the hall table.
- Smooth start "just works" — no openloop tuning needed.

If your motor lacks hall sensors, retrofitting is possible but invasive. Park this until your sensorless tuning hits its limits.

---

## 5. How BREmote interacts with this — and why I'm NOT recommending a BREmote-side fix

### What BREmote can legitimately do (within Section 9 safety)
- **`thr_expo` curve** (0–100, default in your code 100, your planned change 50). At 50 = linear. Below 50 = curve flattens at extremes (more output for mid-trigger inputs). Above 50 = curve sharpens at extremes (less output mid-trigger, more at endpoints).
- For your smooth-start problem, a value around 30–40 *might* help by producing slightly more output at low trigger. But it changes the entire curve, not just startup, and it would feel weird everywhere else.
- **My advice:** keep `thr_expo = 50` (linear) as planned. Let the VESC do its job. Don't compensate for VESC tuning by warping the trigger curve.

### What BREmote is NOT going to do
- **No automatic startup boost** that briefly sends >user-commanded throttle to break the motor free. This would violate Section 9 (creator safety: autonomous modes can only subtract, never add). The boost belongs in VESC where it can be implemented as Q-axis current (motor-aware) rather than as PWM duty (motor-blind).
- **No "smart" throttle remapping** that detects motor stall and pushes harder. Same Section 9 issue, plus the RX has no fast feedback path for motor state — VESC sees this in microseconds, BREmote sees it via 10 Hz telemetry at best.

### Where the boundary is
BREmote's job: deliver the user's trigger position to the VESC over LoRa, faithfully and with predictable safety overrides (RTM cap, failsafe). It does NOT substitute for motor controller tuning. Once the VESC is tuned right, BREmote becomes "boring and correct" — exactly what you want for a safety-critical link.

---

## 5b. Deeper explanation of the two key parameters (added 2026-05-03)

### What is `foc_sl_openloop_boost_q` really?

**The short version:** it's a torque-producing current that VESC adds during the brief startup window when it can't yet sense rotor position from back-EMF. Without it, your trigger has to push enough current itself to break the motor free. With it, VESC supplements your trigger with a controlled "shoulder push."

**The technical version:**
- A FOC motor controller controls current in two perpendicular axes: **D-axis** (parallel to rotor magnets — magnetizes/demagnetizes, makes no torque) and **Q-axis** (perpendicular to rotor magnets — produces all the useful torque).
- "Q" is the torque axis. More Q current = more torque, until the motor is in saturation.
- "Openloop" mode is what VESC does when ERPM is too low for the back-EMF observer to lock on (back-EMF voltage scales with speed; below a few hundred ERPM there's not enough signal). In openloop, VESC just rotates the magnetic field at a programmed rate and assumes the rotor is following.
- `foc_sl_openloop_boost_q` is **extra Q current added during openloop only**. Once the motor reaches the closed-loop transition (`foc_openloop_rpm`), the boost falls away.

**Real-world analogies:**

1. **Pushing a stalled car.** Static friction is much higher than rolling friction. You can't lightly nudge a 2-ton car and expect it to roll — you need to put your shoulder into it. Once it's rolling, gentle pushing keeps it going. The boost is your initial shoulder-push force; once the prop is spinning, the user's normal trigger current is enough.

2. **Pulling a cork from a wine bottle.** You apply a lot of force to break the seal, then almost no force to extract the rest. Without enough initial force the cork doesn't come out at all. Without enough boost, the underwater prop won't break free of static water load.

3. **A diesel truck pulling away from a stop.** The driver applies more throttle to overcome inertia, then eases off once moving. The driver sees the full throttle command. With a passenger car, the engine management does this automatically — that's exactly what `boost_q` does at the motor level.

**What different values of `foc_sl_openloop_boost_q` actually do:**

| Value (A) | What happens to your motor | When this is right |
|---|---|---|
| **0 (current)** | No boost. User trigger must overcome static load entirely. Underwater + prop = needs ~30A motor current = ~35–40% throttle to move. **This is your problem today.** | When motor has hall sensors and openloop is unused, or when load is very light (free spinning fan, no friction). |
| **1–2 A** | Minimal boost. May help slightly. Won't break a heavy underwater prop free at low trigger. | E-skate, e-bike, lightly-loaded scenarios. |
| **3 A** ⭐ recommended start | Mild boost. Combined with ~10–15% user throttle = ~13–18A motor current. Should break a typical e-foil prop free underwater. | Your starting point. Test before going higher. |
| **5 A** | Stronger boost. Combined with ~10% trigger = ~15A motor current. Confident startup at very low trigger. | If 3A isn't enough after bench testing. |
| **8 A** | Aggressive. Motor will eagerly break free even at minimum trigger. Risk: at 0% trigger the motor still tries to spin (boost is added on top of zero). VESC has logic to suppress this when commanded current is exactly zero, but worth confirming. | Heavy underwater loads, large props, tow-buggy hauling adult riders through chop. |
| **10 A** | Hard ceiling I'd recommend. | Extreme cases only. |
| **15+ A** | Risky. Motor windings see this current even at zero RPM (no back-EMF to limit it). Without ventilation/water-cooling, windings can overheat in seconds if rotor is jammed. Battery side sees full draw. | Avoid unless you really know what you're doing and have temperature monitoring. |

**Important: the boost DECAYS automatically as ERPM rises.** Look at `foc_start_curr_dec` and `foc_start_curr_dec_rpm` (yours: `1` and `2500`). VESC reduces the boost smoothly as it transitions from openloop to closed-loop sensorless. So the boost is only present during the first ~1 second of motion. It's not a permanent power add.

**What can go wrong:**
- Too little (0–2): motor doesn't start at low trigger, you need higher trigger to break free. Your current symptom.
- Too much (10+): motor runs warm at idle, draws unnecessary battery, can demagnetize the rotor over many startup cycles in extreme cases (rare).
- Just right (3–8): motor spins reliably at 10–15% trigger, no audible struggle, no excess heat. **This is what you're tuning to.**

---

### What is `foc_openloop_rpm` really?

**The short version:** it's the speed threshold above which VESC trusts its rotor-position observer. Below the threshold, VESC operates blind (forced rotation); above it, VESC has actual feedback and can deliver precise torque.

**The technical version:**
- VESC's sensorless observer estimates rotor position by integrating back-EMF voltage (the voltage induced in the unpowered phases by the spinning rotor's magnets).
- At very low speed, back-EMF voltage is tiny (proportional to ERPM × flux linkage). Below some threshold the signal is buried in noise and the observer's estimate is unreliable.
- `foc_openloop_rpm` defines that threshold. Below this ERPM, VESC ignores the observer and forces a rotating magnetic field at a programmed rate. Above this ERPM, VESC trusts the observer and uses actual position feedback.

**Real-world analogies:**

1. **Speedometer in an old car.** Below 5 mph the needle is jumpy and unreliable. Above 5 mph it reads accurately. If you set your "I trust the speedo" threshold at 5 mph, you drive blind below that and accurately above. Set the threshold too high (e.g., 30 mph), you drive blind for a long time and miss subtle changes. Set too low (e.g., 1 mph), you might trust a noisy reading and steer based on garbage data.

2. **GPS navigation in a tunnel.** No satellite signal = no position. Phones use "dead reckoning" (estimated position based on last known speed and direction) until they get the real signal back. The threshold for "dead reckoning vs real GPS" is analogous to `foc_openloop_rpm` — too long in dead reckoning means you've drifted off the actual position.

3. **A dimmer switch with a deadband.** Below the deadband the bulb is fully off. Above it the bulb dims smoothly. The deadband prevents flickering at the very low end. `foc_openloop_rpm` is the upper edge of FOC's "low-RPM deadband" where it switches from forced behavior to controlled behavior.

**What different values of `foc_openloop_rpm` actually do:**

| Value (ERPM) | What happens | When this is right |
|---|---|---|
| **500** (very low) | VESC trusts observer almost immediately. Best low-speed control if observer is accurate. **Risk:** if motor params drift (cold motor, water temperature changes, prop fouling), observer can give wrong position → motor stutters, faults, runs backward. | Motors with very stable parameters and very accurate auto-detection. Bench setups, lab conditions. |
| **800–1000** ⭐ recommended for you | Observer takes over early. Smooth transition from openloop to sensorless. Good low-speed feel without observer stress. | Most well-detected motors with stable conditions. **My recommendation for Step 2 of your tuning.** |
| **1500 (your current default)** | Conservative transition. Stays in openloop longer. Reliable startup, but low-speed control feels a bit "wooden" because openloop is blind. | Motors that struggle to lock on to back-EMF — usually means R/L params need re-detection. |
| **2500** | Very conservative. Stays in openloop until clearly above startup speed. Stable but low-speed control is genuinely poor. | Motors with bad parameter detection, high-noise environments, or cases where the observer keeps faulting. |
| **5000+** | Essentially permanent openloop until you're cruising. VESC never feels the rotor's actual position at low speed. Awful low-speed control, but unkillable startup. | Last-resort tuning when nothing else works. |

**Why lower is generally better (within reason):**
- Closed-loop sensorless gives you ACTUAL torque control. Trigger goes up, observer sees rotor lagging, more current is applied to catch up. Smooth.
- Openloop gives you FORCED rotation at a fixed rate. Trigger goes up, the boost current rises but the rotation rate is whatever VESC programmed. The rotor either follows or doesn't. There's no closed-loop "I want more torque" feedback.

**Why too low is bad:**
- The observer needs back-EMF signal to estimate position. Below the noise floor, it just produces garbage.
- Garbage estimates in closed-loop mode = motor commanded to wrong angle = commutation error = motor stutters, vibrates, or runs backward.
- Symptom: motor starts to spin during openloop, then at the transition point it suddenly jerks/stops.

**The sweet spot for your motor:**
You have a 6384 outrunner with decent R (0.023Ω) and L (18µH) and good auto-detection. Observer should lock cleanly at 1000 ERPM. Going to 800 might give even smoother low-speed feel but increases risk of bad detection days. **Start at 1000, drop to 800 only if 1000 feels rough.**

**Interaction with `foc_sl_erpm_start` and `foc_sl_erpm`:**
- `foc_openloop_rpm` (1500): below this, full openloop.
- `foc_sl_erpm_start` (your 2500): above this, sensorless **starts** taking over (blend zone begins).
- `foc_sl_erpm` (your 3400): above this, sensorless is **fully** in charge (blend complete).

So your actual transition zone is 1500 → 2500 → 3400 ERPM. That's a 2000-ERPM blend window. Lowering all three (1000 / 1500 / 2500 in my recommendation) shifts the entire transition window down ~1000 ERPM, putting smooth control in your usable speed range.

---

## 6. FOC config file — clean copy of recommended changes

If you want to apply changes via XML import (not via the wizard), the diff against your current config:

```xml
<!-- BEFORE -->
<foc_sl_openloop_boost_q>0</foc_sl_openloop_boost_q>
<foc_openloop_rpm>1500</foc_openloop_rpm>
<foc_sl_erpm_start>2500</foc_sl_erpm_start>
<foc_sl_erpm>3400</foc_sl_erpm>

<!-- AFTER (Step 1 only — start here, conservative) -->
<foc_sl_openloop_boost_q>3</foc_sl_openloop_boost_q>
<foc_openloop_rpm>1500</foc_openloop_rpm>
<foc_sl_erpm_start>2500</foc_sl_erpm_start>
<foc_sl_erpm>3400</foc_sl_erpm>

<!-- AFTER (full recommendation if Step 1 helps but isn't enough) -->
<foc_sl_openloop_boost_q>5</foc_sl_openloop_boost_q>
<foc_openloop_rpm>1000</foc_openloop_rpm>
<foc_sl_erpm_start>1500</foc_sl_erpm_start>
<foc_sl_erpm>2500</foc_sl_erpm>
```

**Don't apply both at once.** Step 1 first, test, then Step 2-3 only if needed. One change at a time = easy to back out if anything goes wrong.

---
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

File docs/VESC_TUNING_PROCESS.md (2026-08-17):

# VESC Smooth-Start Tuning Process — Iterative Method with Log Analysis

For: Andres, BREmote V2.5-EVO + FlipSky FSESC 75200 V2 + 6384 outrunner + sensorless FOC underwater
App: VESC Tool 6.06 (Android, Google Play)
Date created: 2026-05-03
Companion docs: `VESC_SMOOTH_START_QUICK_REFERENCE.md`, `VESC_FOC_TUNING_NOTES.md`, `THROTTLE_PIPELINE_ANALYSIS.md`

---

## TL;DR — your current symptom and the immediate next move

**Symptom:** With boost = 3 the motor starts well from cold-stop, but if you partially release the trigger and re-engage WHILE THE MOTOR IS STILL SPINNING DOWN, you get "duck-duck-duck" stutter, sometimes catches, sometimes doesn't, sometimes you have to wait until full stop before it'll restart.

**Diagnosis:** Classic spinning-restart problem in sensorless FOC. The motor is rotating at, say, 500–1000 ERPM (still spinning down). Your `Open loop ERPM` threshold is 1500, so VESC sees the motor as "below sensorless" and tries to forcibly restart in openloop mode. But the forced rotation rate clashes with the actual rotor angle → each "duck" is a bad commutation cycle until the rotor either catches up or fully stops.

**Fix (Step 2 in the original guide):** Lower **`Open loop ERPM`** from **1500 → 1000**. With 1000, the observer takes over at 1000 ERPM. When you re-engage at 800–1000 ERPM, the observer locks onto the actual rotor position immediately — no openloop forcing, no clash, smooth resume.

This is your next single change. After bench-testing it, you decide whether to go further (Step 3 lowers `foc_sl_erpm_start` and `foc_sl_erpm`).

---

## 1. THE PROCESS (the loop you'll follow forever)

Tuning a sensorless FOC motor is iterative. You change ONE parameter, test it under a defined condition, observe the result (symptom + log), decide the next change. The doc you're reading is the methodology.

```
┌──────────────────────────────────────────────────────────┐
│  1. SET BASELINE                                          │
│     BREmote: throttle_mode=1, thr_expo=50 (linear)        │
│     RTM: disarmed, system unlocked                        │
│     This eliminates BREmote-side curve interference so    │
│     trigger position correlates 1:1 with motor command.   │
├──────────────────────────────────────────────────────────┤
│  2. SAVE CURRENT VESC CONFIG AS XML (rollback point)     │
│     Motor Settings → menu → Save XML                      │
│     Name it: motor_<date>_<change>.xml                    │
├──────────────────────────────────────────────────────────┤
│  3. CHANGE ONE PARAMETER                                  │
│     Write to VESC, Save to flash                          │
├──────────────────────────────────────────────────────────┤
│  4. RUN A DEFINED TEST                                    │
│     With logging enabled (see §2 below)                   │
│     Each test is one of: cold start, restart-while-       │
│     spinning, full-throttle ramp, sustained low throttle  │
├──────────────────────────────────────────────────────────┤
│  5. SAVE THE LOG (CSV) AND OBSERVE THE SYMPTOM            │
│     Note: trigger position, audible behavior,             │
│     visual smoothness, any faults.                        │
├──────────────────────────────────────────────────────────┤
│  6. INTERPRET (see §4 diagnosis matrix)                   │
│     If better: keep the change. If worse: load rollback.  │
├──────────────────────────────────────────────────────────┤
│  7. NEXT PARAMETER (if needed) — go back to step 2        │
└──────────────────────────────────────────────────────────┘
```

**Iron rule: change ONE parameter at a time.** If you change three things and something improves, you don't know which change did it. If something gets worse, you don't know which change broke it.

---

## 2. HOW TO RECORD VESC LOGS IN THE ANDROID APP (VESC Tool 6.06)

### 2.1 First-time setup (do this once)

1. Open VESC Tool 6.06.
2. Connect to the FSESC over Bluetooth.
3. Go to **Settings** (gear icon) or the side menu → **Developer**.
4. **"Choose File folder"** — pick a folder on your phone storage. Easiest: `Downloads` or create a new folder called `VESC_logs`.
5. Tick **"Enable RT Data Logging"**.
6. Tick **"Log to CSV"** (if separate option).
7. Close settings.

If you get "Could not open file for writing" — create a new folder via Files app first, then re-pick that folder in VESC Tool's Developer settings. Restart the app if needed.

### 2.2 Per-session recording

Each tuning test:

1. Connect to FSESC.
2. Go to **Real-Time Data** (or **Realtime → RT Data**).
3. Tap the **record / log button** (usually a red dot or "Start logging" icon at top).
4. **Run the test** (see §3 below for what tests to run).
5. Tap **stop logging**.
6. The CSV is saved to your chosen folder with a timestamp filename.
7. Optionally rename the file to describe what you tested, e.g.:
   - `2026-05-03_boost3_restart-while-spinning.csv`
   - `2026-05-03_boost3_openloopRPM1000_coldstart.csv`

### 2.3 What ends up in the CSV
The CSV typically contains these columns (one row every ~50ms during recording):
- Timestamp (ms or s since recording started)
- Voltage (input battery)
- Motor RPM (mechanical)
- ERPM (electrical RPM = mechanical × pole pairs)
- Duty Cycle (0–1)
- Battery Current (A)
- Motor Current (A) — Q-axis
- Motor Temperature (°C)
- ESC Temperature (°C)
- Fault Code (0 = no fault)
- Position (electrical angle)
- Other auxiliary fields

The most useful for tuning: **ERPM, Motor Current, Duty Cycle, Fault Code, and time**.

---

## 3. THE THREE TESTS YOU'LL RUN EVERY ITERATION

Run each test with logging on. Each isolates one behavior. Don't skip — the whole process depends on knowing which behavior changed.

### Test A — COLD START
- Motor fully stopped (wait at least 3 seconds after last spin).
- From rest, ramp trigger smoothly from 0% to 30% over ~2 seconds.
- Hold at 30% for 2 seconds.
- Release.
- **What we're checking:** does the motor break free smoothly? At what trigger %? Any audible chirp/stutter at the transition?

### Test B — RESTART-WHILE-SPINNING (your current pain point)
- Bring motor to 50% trigger, run for 2 seconds.
- Release trigger fully (motor coasts down).
- After **0.5 seconds** of coasting, re-engage at 50%.
- Release. Wait for full stop.
- Repeat with **1.0 second** coast time, then **2.0 seconds**, then **5.0 seconds**.
- **What we're checking:** at what coast duration does the duck-duck stutter happen? At what duration does it go away? This tells us exactly which ERPM range the observer is failing in.

### Test C — SLOW LOW-THROTTLE CRUISE
- From rest, slowly bring trigger to 15% over 5 seconds. Hold at 15% for 10 seconds.
- Slowly release.
- **What we're checking:** is sustained low-throttle smooth? Any vibration or growl? Is the motor producing useful thrust at 15%?

---

## 4. DIAGNOSIS MATRIX — SYMPTOM → CAUSE → PARAMETER TO CHANGE

| Symptom | Likely cause | First parameter to try | Notes |
|---|---|---|---|
| Motor needs >25% trigger to break free from cold stop | Boost too low for static load | **Open loop current boost +1 to +2 A** | You're at 3, try 5 if cold-start is still hesitant |
| Duck-duck-duck stutter when re-engaging mid-spin | `Open loop ERPM` threshold too high → openloop forces commutation against still-spinning rotor | **Lower `Open loop ERPM` 1500 → 1000** | This is your next move |
| Motor starts then jerks at "transition" point | Sensorless ERPM threshold mismatch — observer not ready when openloop hands off | **Lower `Sensorless ERPM Start` 2500 → 1500 AND `Sensorless ERPM` 3400 → 2500** | Step 3 — only after Step 2 verified |
| Motor jumps suddenly at 0% trigger | Boost leaking with zero command | **Lower boost** (try 2 if currently 3) | Verify VESC firmware is recent enough to suppress boost at zero command |
| Motor very hot at low throttle | Boost too high, dissipating real I²R losses in stalled windings | **Lower boost** | Hard ceiling: 8 A. If hot at 3 A, something else is wrong (mechanical bind, prop fouled). |
| Motor commutates wrong direction occasionally | Observer giving bad estimates during transition | Lower `Open loop ERPM` slowly, retest | If persistent, motor parameters may have drifted — re-run Motor Detection. |
| Audible whine at idle (above 3 A boost) | High-frequency PWM artifact | Try lowering `foc_f_zv` from 30000 to 25000 (FOC → General) | Cosmetic; not safety-relevant |
| Fault code 6 (Undervoltage) on spin-up | Battery sag from inrush + boost current | Lower `l_in_current_max` if you want gentler inrush, OR lower boost | Check battery health first |
| Fault code 11 (Encoder Spi error) | Not relevant — sensorless mode | Ignore | Only matters for sensored setups |

---

## 5. WHAT TO LOOK FOR IN THE CSV

Open the CSV in a spreadsheet (Excel, Google Sheets, or even a phone CSV viewer). Plot or scroll through these columns over time. Focus on the section where the symptom occurred:

### Pattern: smooth start (good)
- ERPM: ramps cleanly from 0 to several thousand in ~1 second
- Motor current: rises to a peak (~5–15 A) then settles down once spinning
- Duty cycle: rises smoothly with ERPM
- Fault: 0 throughout

### Pattern: duck-duck-duck (bad)
- ERPM: stays low (300–1000) and oscillates, doesn't climb
- Motor current: spikes up and down, alternating high/low
- Duty cycle: also oscillates
- This is the "openloop forcing the wrong angle" signature
- Fault: 0 (it's not actually faulting, just stuttering)

### Pattern: undervoltage trip
- Voltage: dips below `l_battery_cut_end`
- Fault code: jumps to 6
- Motor current then drops to 0

### Pattern: motor commutating backward
- ERPM: goes negative then positive then negative
- Motor current: reverses direction repeatedly
- This is a serious observer failure — re-run motor detection

### What "good" looks like for Test B (restart-while-spinning)
- During coast: ERPM gracefully decreases, Motor Current ≈ 0 (no torque)
- At re-engage: ERPM should JUMP to track the new trigger, NOT drop to 0 first and try openloop
- Motor current spikes briefly then settles
- No oscillation in ERPM

---

## 6. APPLYING THE PROCESS TO YOUR CURRENT STATE

You're at:
- Boost = 3 ✅ (Step 1 done, motor breaks free reasonably)
- Open loop ERPM = 1500 (default — needs to come down)
- Sensorless ERPM Start = 2500, Sensorless ERPM = 3400 (defaults — Step 3 territory)

**Do this in order:**

### Iteration A (next session)
1. Save current XML as rollback: `motor_2026-05-03_boost3_baseline.xml`
2. Run Tests A, B, C with logging on. Save logs as `iter_A_<test>_2026-05-03.csv`.
3. Change ONE parameter: `Open loop ERPM` from 1500 → 1000. Write to VESC, save to flash.
4. Run Tests A, B, C again with logging on. Save as `iter_B_<test>_2026-05-03.csv`.
5. Compare:
   - Test B should show much less duck-duck stutter (the symptom should be largely gone)
   - Test A should still be smooth (didn't break Step 1)
   - Test C should be smooth or smoother
6. **If duck-duck is gone:** keep the change, move to Iteration B if you want even tighter low-speed feel.
7. **If duck-duck got better but not gone:** lower `Open loop ERPM` to 800. Repeat tests.
8. **If anything got worse:** load rollback XML, write to VESC, save. Try a different change.

### Iteration B (only if A's duck-duck is fully fixed and you want sharper low-speed control)
1. Save XML rollback first.
2. Lower `Sensorless ERPM Start` from 2500 → 1500.
3. Lower `Sensorless ERPM` from 3400 → 2500.
4. Run Tests A, B, C. Compare logs.
5. If smoother: keep. If anything stutters during transition: roll back and stop here.

### Iteration C (advanced — only if you've optimized A and B and still want more)
- Try `Open loop lock time` from 0 → 0.05 s. Gives the rotor a moment to align with the openloop start angle. May help cold start at lower boost. May make hot-restart slightly worse (so test B carefully).
- Try `foc_f_zv` (PWM frequency) from 30000 → 25000 in FOC → General. Quieter operation, slightly less precise control.

**Stop iterating when good enough.** Perfect is the enemy of done. If A fixes the duck-duck and the motor feels good, ride it. Don't tune for tuning's sake.

---

## 7. ABOUT PHASE FILTER (intentionally NOT recommending — read this)

You may see suggestions on the VESC forum to enable **Phase Filter** (`foc_phase_filter_enable`) for spinning-restart issues. **DO NOT enable this on the FlipSky FSESC 75200 V2 without first verifying the hardware supports it.**

Phase filter is a SOFTWARE feature that requires HARDWARE — specifically, voltage-divider capacitors of at least 220 nF on the phase voltage sense lines. The FlipSky 75200 V2 may or may not have these (the 75100 and 75200 hardware threads on vesc-project.com discuss this in detail and the answer depends on board revision).

If you enable phase filter on hardware that doesn't support it, behavior includes:
- Negative current readings during detection
- Wrong R/L/flux measurement on motor detection
- Worse low-speed performance, not better

**The fix for your current symptom (lower `Open loop ERPM`) does not depend on phase filter and is safe regardless of hardware.** Save phase filter for last-resort tuning if Step 2 + Step 3 don't fully solve it. If you want to try it, first ASK on the FlipSky forum thread or VESC project forum whether the 75200 V2 has the right cap value. Don't guess.

---

## 8. UPLOADING LOGS FOR ANALYSIS

When you have a log file you want analyzed:

1. **Save the CSV** to your phone's chosen log folder.
2. **Transfer to your computer**, easiest via Google Drive: drop the CSV into your existing project folder structure or a new subfolder, e.g.:
   - `<your project folder>/Vesc and other related files/logs/`
3. **Name it descriptively:**
   - `iterA_boost3_openRPM1500_testB_restart_2026-05-03.csv`
   - Format: `iter<X>_<changed-params>_test<Y>_<symptom>_<date>.csv`
4. **Tell me in chat:** "I uploaded `iterA_boost3_openRPM1500_testB_restart_2026-05-03.csv` for analysis. The symptom was duck-duck-duck on re-engage at 1.0s coast time."
5. I'll read it, look for the patterns described in §5, and recommend the next single change.

### What I need to know with each upload
- Which iteration (A, B, C…)
- Which test (cold start / restart-while-spinning / slow cruise)
- What you changed since the last log
- What the audible/visual symptom was
- What the trigger sequence was (so I can correlate with the time axis)

The more structured your reports, the faster the diagnosis. If you just upload `vesc_log_2026-05-03_153012.csv` with no notes, I'll have to reconstruct what happened from the data, which is slower and error-prone.

---

## 9. SOURCES

- [Flipsky FSESC75100 & FSESC75200 Phase Filtering — VESC Project](https://vesc-project.com/node/3529)
- [Sometimes startup problems in FOC-Mode — VESC Project](https://vesc-project.com/node/85)
- [VESC 6.0 Data Logging? — VESC Project](https://vesc-project.com/node/77)
- [VESC tool for Android — VESC Project](https://vesc-project.com/node/2772)
- [Data logging — VESC Project](https://vesc-project.com/node/932)
- [Vesc tools log how to — FOIL.zone](https://foil.zone/t/vesc-tools-log-how-to/18244)
- [VESC Tuning tips — Endless Sphere](https://endless-sphere.com/sphere/threads/vesc-tuning-tips.125527/)
- Companion docs in this folder: `VESC_SMOOTH_START_QUICK_REFERENCE.md`, `VESC_FOC_TUNING_NOTES.md`, `THROTTLE_PIPELINE_ANALYSIS.md`

---

End of process doc.

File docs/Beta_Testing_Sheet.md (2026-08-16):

# BREmote V2.5-Evo — Beta Tester Guide

Welcome, and thanks for testing. Read the hardware section first — the settings below are tuned for **my** exact setup. If yours differs, my numbers are a starting point, not gospel.

---

## 0. My hardware (what these settings assume)

| | My setup | If yours differs |
|---|---|---|
| **Motor** | Flipsky **6384, sensorless**, **custom 170 KV** | Off-the-shelf 6384 is ~140 KV. Run your own motor detection. |
| **Poles** | 14 (7 pole pairs) | Set to your motor's poles. |
| **Battery** | **10S** Li-ion | Most people run 12S/14S. My voltage cutoffs are 10S-specific — change them. |
| **ESC** | VESC (FW 6.x), **one per motor** (dual-motor differential steering) | — |
| **Control** | **PPM + UART** from the BREmote RX, one signal wire per VESC | — |
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

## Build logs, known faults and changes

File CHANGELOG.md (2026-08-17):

# Changelog

## 2026-08-16 — RX SW35: the compass knows how it is mounted (⚠️ resets your RX settings once)

**Recommended: reflash the RX. Back it up first.**

### ⚠️ This one resets your RX configuration

`confStruct` grew from 184 to 192 bytes, so the RX rewrites its config to defaults on the first
boot after this flash. **Print a backup with `?conf` before you flash**, restore afterwards with
`?setconf <blob>` then `?applyconf`, then re-pair and re-run `?compasscal`. You want that
calibration run anyway — it is what sets the new mounting orientation.

Moving between two **SW35** builds resets nothing. It is only the 34→35 step (and a 35→34
rollback) that costs you the config and the compass calibration.

### Compass mounting orientation — `?compasscal` measures it for you

Heading is `atan2(y, x)` on the sensor's own axes. Mount the module rotated and every heading was
wrong by that angle — and the old calibration was blind to it, because a rotation leaves the
calibration circle centred and round. Nothing looked wrong. Mount it **square** — lined up with the
nose or turned exactly 90°, 180° or 270° from it, never diagonal, since the rotation is stored only as
one of those four values — then tell the firmware once:

```
Point the nose of the buggy at NORTH
Run ?compasscal  (or short-press BIND)
Rotate SLOWLY CLOCKWISE, two full circles
Finish with the nose back on NORTH
```

Clockwise is how handedness is detected. Ending on north is how the result is checked. One run
now produces three things: the hard/soft-iron calibration as before, the mounting **handedness**
(a mirrored module is stored as a negative `mag_scale_y`), and the mounting **rotation**, snapped
to 0/90/180/270.

A run too sloppy to trust **stores nothing rather than storing a guess** — the iron calibration is
still saved and the previous orientation is kept, and the report says plainly what was and was not
updated instead of printing "Success!" either way.

**New: `?magalign`** sets the mounting orientation on its own — point the nose at magnetic north,
run it, done — so orientation can be re-checked without redoing the slow two-circle iron sweep. It
refuses to run on an uncalibrated compass, and warns if the reading was more than 25° off the
nearest cardinal.

### Return-to-Me: no longer steers on a compass caught lying

A beta tester's buggy tracked straight toward him, then turned hard at 5–7 m. RTM decelerates
inside the approach zone, speed falls below the COG minimum, and heading hands over from GPS
course to the compass — and a rotated compass makes the heading **step** by the mounting angle at
exactly that moment.

Two guards existed and neither fired: the per-tick cross-check could only run while GPS course was
still trustworthy, and the sticky disagree fault was read only by Follow-Me — Return-to-Me never
read it. The check now sits at the source, in `getRtmHeading()`, so a discredited compass is not
handed out to RTM, to FM, or to anything added later. RTM holds straight instead, which at close
range is the safe outcome.

**A GPS course that was valid moments ago is now held for 3 seconds** before falling back to the
compass. RTM governs to 4.0 km/h and abandons course below 3 km/h — a 1 km/h margin that sits
inside the speed signal's own noise, so the heading source was flipping on noise alone and handing
steering to a compass badly wrong under motor load. A two-second-old course beats an inverted
compass.

### Heading mode: the COG-only trap is repaired for you

`rtm_use_compass 0` (GPS course only) combined with `rtm_compass_required 1` meant RTM could never
arm — that gate does not check for a compass despite its name, it demands a valid heading of any
kind, and there is none while the buggy sits still with the compass off. It failed with
`STOP: No valid heading source` and read like COG-only mode was broken.

Setting `rtm_use_compass 0` now clears `rtm_compass_required` automatically and prints why. It is
enforced on every save path including boot, so an old config backup carrying the trap is repaired
rather than leaving RTM unarmable.

The Follow-Me engage-distance floor now behaves the same way: a too-small value is **clamped up**
to the 8 m tow-rope minimum with a printed explanation, instead of failing validation and taking
every other setting down with it.

### TX: far fewer vibrations

A rider holding the remote while concentrating on a wave does not decode vibration patterns — they
feel *a buzz*. Seventeen trigger sites across seven patterns is not a language, it is noise. Six
triggers are gone: disarming RTM by steering, disarming FM, selecting F0, and cycling FM modes —
things **you** just did, where the display already shows the result. Everything that tells you
something you did not already know is kept.

Informational buzzes now wait for one already playing to finish rather than overwriting it; two
patterns colliding is what made them unreadable.

### Audit fixes before publication (`a8f8512`)

A pre-publication audit found several things this release announced that were not true in the
shipped code. None touched the motor path; four were user-visible and one shipped inside the
published binary. `confStruct` is unchanged at 192 bytes and `SW_VERSION` stays 35, so this is a
drop-in rebuild — no config wipe, no re-pairing, no re-calibration.

- **The RX's own WiFi config page was dead** in the published SW35 binary — the field array was
  never terminated and a block was deleted with it, so the page rendered nothing and no button
  worked. `gps_dyn_model` had also been spliced inside `gps_chip_type`'s options and four fields
  were missing. Repaired and reconciled 1:1 against the firmware's field table. **Eleven default
  values were wrong** — the page claimed the factory defaults were GPS off, telemetry off, EU868
  and Kalman off, when the shipped defaults are the opposite.
- **`gps_dyn_model` was honoured only on the legacy M8 path.** Both CFG-VALSET paths hardcoded
  Sea, so an M9/M10 owner above the 500 m ceiling silently kept Sea. Now single-sourced. The baud
  scan also recognises a checksum-verified UBX frame, so a module left UBX-only by a drone flight
  controller is detected instead of reported dead — detection stays listen-only and transmits
  nothing. NMEA output on UART1 is re-enabled on the VALSET path.
- **Compass:** an under-rotated re-calibration silently destroyed a stored mirror correction, and a
  motionless run saved a noise blob over a good calibration. Both refused now. QMC5883P init writes
  are checked — a failed axis-sign write reports the compass as absent rather than producing
  plausible wrong headings.
- **The heading-disagree backstop could never fire.** The Follow-Me idle path cleared its latch on
  every 100 ms tick, including while RTM was running, so the dwell never accumulated in the one
  mode the guard was written for. Cleared on state transitions only now, and a disagreement must be
  continuous. The COG hold is mirrored into the logger so logs stop misattributing the heading
  source during exactly the transitions those logs are read to diagnose.
- **22 bench commands could freeze the loop task mid-ride**, suspending every autonomous safety
  gate while the last steering override and throttle cap kept being applied. The worst were the
  streamers that run until you type `quit`, and `?download`. They now refuse to start while RTM or
  Follow-Me is engaged, and abort if an engagement begins after they started — the physical BIND
  button included. `?gpssetup` and `?wifiupd` are deliberately **not** abortable: interrupting them
  leaves the GPS module or the stored web UI worse than letting them finish. The watchdog now also
  arms on the first boot after a version bump, previously the one boot that ran without it.
- **A config blob that failed validation was already live** — copied into the running struct before
  being checked, and the result ignored. It now validates into a staging copy first, `?applyconf`
  reports pass or fail, and `?setconf` explains why a backup was rejected instead of failing
  mysteriously two steps later. Shared with the TX, which picks this up at its next rebuild.

---

## 2026-08-16 — RX: a GPS dynamic model you can set

**No config wipe.** This one reuses a reserved slot renamed in place, so `sizeof(confStruct)` stays
184 and `SW_VERSION` stays 34.

The RX hard-coded u-blox dynamic model 5 (Sea). The code comment said the ceiling was deliberate
and that this buggy would never be run above 500 m. The first beta tester to fit an M100-5883 lives
at 550 m — the documented limit was hit within three weeks, by the first outside user.

`gps_dyn_model` is now a setting:

| Value | Model | Use it when |
|---|---|---|
| **0** | default → Sea | **Leave it here.** What every board already does. |
| **4** | Automotive | **You ride above ~500 m altitude.** Sea has a 500 m ceiling and fixes degrade above it. |
| **5** | Sea (explicit) | Same as 0, stated outright. |

```
?set gps_dyn_model 4
?save
```

Reboot; the boot log then reads `dynModel=Automotive`.

**Sea stays the default** because below 500 m it is genuinely better: it constrains the filter to
~25 m/s and pins altitude near the surface, which sharpens course-over-ground — and course is what
Follow-Me actually steers on. Switching everyone to Automotive would cost every sea-level rider
that sharpening to fix a problem they do not have.

**Portable is not offered anywhere.** It permits 310 m/s and is what produced the bogus 254 km/h /
4800 m *high-confidence* fixes this whole line of work exists to prevent. Anything that is not an
explicit `4` resolves to Sea, so a corrupt or out-of-range value fails toward the conservative
model. Every board in the field holds `0` in that slot, which is why `0` means exactly what the
firmware did before the field existed.

---

## 2026-08-15 — RX: one image drives either compass

**No config wipe.** No `confStruct` change, no `SW_VERSION` bump — the I²C address *is* the
identification, so there is nothing to set and nothing to get wrong.

The RX hard-coded one magnetometer: a QMC5883L at `0x0D`, which is what a BN-880 carries. The
**HGLRC M100-5883** carries a **QMC5883P** at `0x2C`, so the RX simply did not see it — no compass,
10 blinks, no Follow-Me heading. It now detects which part is fitted at boot and drives it
correctly:

| I²C address | Part | Found on |
|---|---|---|
| `0x0D` | **QMC5883L** | Beitian BN-880, HGLRC M100 Pro |
| `0x2C` | **QMC5883P** | HGLRC M100-5883 |
| `0x1E` | HMC5883L | very old BN-880 stock — reported, **not** driven |

**Why this needed a real driver and not just a new address.** These are different silicon, not a
revision, and the data block starts at a **different register** — `0x00` on the L, `0x01` on the P.
Point the L's driver at a P and every axis is shifted one byte, with the chip ID as X's low byte.
It does not error and it does not look broken: it returns a smooth, plausible, completely wrong
heading. On a buggy that steers itself toward a rider in the water that is a safety failure, not a
cosmetic one. The read path branches on the detected part for exactly that reason.

Prompted by a pull request from **robertzach**, who got an M100-5883 working on his own fork.
Implemented independently rather than merged, because that change *replaces* the QMC5883L path
rather than adding to it — merging it as-is would have broken every BN-880 build.

> ⚠️ **Re-run `?compasscal` after changing GPS or compass module.** Stored `mag_offset_*` values are
> raw counts and do not survive a part change. The firmware prints this reminder at boot.

---

## 2026-08-15 — TX: GPS config replies are now checksum-verified

**No config wipe.** `SW_VERSION` stays 27; all three SW27 builds are interchangeable.

`ubxPoll()` returned the instant it had collected the payload and **never read the two checksum
bytes at all**. Any byte sequence in the stream that happened to look like a valid UBX header was
believed — and that stream carries NMEA and UBX at 5 Hz, so a chance match on four header bytes is
entirely plausible.

That function feeds the dialect detection which decides whether your module speaks the legacy
u-blox 6/7/8 command set or the M9/M10 `CFG-VALSET` set, and `?gpssetup` writes in whichever
dialect it reports. **A false verdict means the module is sent commands it cannot parse and
configuration fails silently** — no error, just a module that was never configured.

Not hypothetical: the RX carried the identical defect and reported a BN-880 — a u-blox M8, which
has no `CFG-VALGET` at all — as "M9/M10" on three consecutive runs. Fixed on the RX on 2026-08-02;
this is the same fix applied to the TX copy that was missed.

The fix accumulates the Fletcher-8 checksum across class, id, length and payload, then verifies
`CK_A` and `CK_B` before returning. A wrong checksum resyncs and keeps looking.

---

## 2026-07-25 — GPS heading fix (Alpha, pending on-water testing)

**Recommended: reflash both TX and RX.**

### The bug
The receiver has **one serial line shared between the GPS and the VESC**, switched back and forth by a multiplexer. The switching had the priority backwards: it sat on the VESC and only glanced at the GPS for 10 milliseconds, twice a second.

The GPS talks in bursts, so that window almost always landed in the silence between bursts. **The receiver was catching about 2% of what the GPS said** — roughly one course update every 25 seconds.

With no live course, Follow-Me fell back to the compass. The compass is snapshotted while the motor is idle and can't refresh while you're holding the trigger, so it went stale mid-run — **and the buggy steered the wrong way with nothing detecting it.**

The 10 ms delay turned out to be leftover code guarding something that had been deleted long ago. The multiplexer actually switches in under 3 microseconds.

### The fix
**Priority swapped: the line now rests on the GPS, and the VESC is the visitor.** Measured on hardware:

| | Before | After |
|---|---|---|
| GPS sentences per second | 0.1 | **84.8** |
| GPS fix | none | **holds a fix, 23 ms old** |
| VESC telemetry success | 72% | **100%** |
| Worst-case loop time | 239 ms | **29 ms** |

It also uses **fewer** multiplexer switches than before, not more.

### Also fixed
- **Follow-Me now refuses to steer on a dead heading.** A GPS course that stops changing is no longer treated as live just because its timestamp keeps updating, and a frozen course no longer silently hands steering to the compass. If the compass and GPS disagree by more than 45°, neither is trusted and the buggy holds straight.
- **New safety net:** if Follow-Me stops actually following — beyond twice the engage distance and not closing — it stops and hands control back.
- **Signal bar was reading low on a healthy link.** The scale bottomed out ~18 dB too early, which also caused false weak-signal buzzes.
- **Distance display:** the decimal dot now always means a decimal. It used to mean "×100" above 100 m, so 170 m showed as `1.7` and read as 1.7 m. Now `17` is 17 m, `1.7` is 1.7 m, and 100 m or more scrolls **FAR**. Metres only this version.
- **Follow-Me engage distance is now a real setting** — measure your tow rope and set at least a metre beyond it. Minimum 8 m, enforced. A value shorter than your rope would let Follow-Me engage while you're still being towed.
- **Log downloads over WiFi were missing five columns** (including signal strength) and reported **motor RPM 10× too low**. Both export paths now match.
- **Logging levels added** (`log_level`, 0–4). Level 4 records deep diagnostics — GPS throughput, whether the course is actually changing, I²C errors, worst loop time — so a session can be diagnosed from its log.
- **Compile fix:** the RX build reported "97% of program storage" and would have refused to build with ~800 KB still free. Use `PartitionScheme=custom` — see the RX flashing guide. Your partition layout is unchanged; only the size check was wrong.

### Still alpha
**This is fixed but not yet proven on the water.** The measurements above are bench and bucket tests. On-water validation is next. Test at your own risk, keep manual control in reach, and report anything you see.

Your saved settings are **not** wiped by this update.

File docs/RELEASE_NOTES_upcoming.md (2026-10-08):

# Upcoming release — notes for riders

> **🌙 nightly firmware.** These notes describe the **nightly** firmware on the
> [`fm-stations` branch](https://github.com/monterman/BREmote-V2/tree/fm-stations), not the firmware
> on master. Nightly = bleeding edge, under water testing, use at your own risk. Binaries are in the
> `latest-FM-stations` folders. Its commits move to master gradually after more water testing.

Remote (TX) SW 27 and buggy (RX) SW 36, both V2.5-Evo.

## Before you flash

1. **Download all your logs from the buggy.** The log format changes to 3; after the flash the
   buggy can't open files from older firmware (the PC log reader on the branch still can).
2. **Back up your settings** on both boards ([how](../README.md#-backing-up-your-settings--read-this-before-you-flash)).
   Your stored settings are kept by this flash, but a backup costs a minute.
3. **Flash the remote and the buggy together.** The new screens need both.
4. Bench-test wheels up before the water.

## What's new

**Follow-Me screens.** One dot hopping = waiting. Two steady dots = following. The dot column
filling down = the buggy is coming to you. The numbers are metres between the remote and the
buggy. [See them animated, with a glance quiz.](https://monterman.github.io/BREmote-V2/followme-screens.html)

**Auto-return.** Stop, and the buggy parks and waits while you surf, swim or pump back. Squeeze
the trigger and it comes back to you. Pausing or letting go never cancels it. It ends when it
arrives, on a fault (St), or when you switch the remote off and on.

**Arrival is safe at full throttle.** When a returning buggy reaches you, steering is yours again
at once, but the throttle stays limited until you let go of the trigger once.

**Magnet tap** (`mag_mode` 4). Tap to arm Follow-Me, even on the rope; tap again while following
to step the station. Hold 2.5 s with the trigger released to start the manual return-to-me.

**Gestures need a released trigger.** The return gestures only start with the trigger fully
released, so steering a returning buggy can't start or cancel anything by accident. A magnet tap
still arms Follow-Me on the rope. A 1 s LEFT hold during the "rn" window cancels the return-to-me
back to full manual.

**Front stations F4 / F5\*.** Ahead-right and ahead-left, for downwind runs. Never dead ahead,
about 13 m (43 ft) to the side, extra distance forward, and a protection cone around your path that
the buggy never cuts through. *\* In development and testing, not yet water-tested. The buggy side
is in; picking F4/F5 from the remote comes in a later remote update.*

**Serial console on the buggy's WiFi page** (RX only). From your phone at the dock or the beach:
a dropdown of the commands the buggy allows over WiFi, a free-text box, and one-tap buttons for
everyday jobs (Save, `?get`, North check, compass align, `?diag`, `?conf`, `?printgps`,
`?logstat`). Save checks for free space first, so a nearly full buggy can't silently lose your
settings.

**Throttle-input fault protection.** If the remote's trigger sensor stops answering (water, a stuck
sensor bus), the throttle goes to zero and the screen blinks St. It used to hold the last value.

**Motor needs a fresh throttle command.** The buggy only runs the motor on a fresh throttle packet,
not just a live radio link.

**Fewer buzzes.**

| Buzz | Means |
|---|---|
| two short taps | armed |
| one long + St | stopped, refused or a fault |
| five short | link lost |
| five long + E 7 | water in the buggy |
| two short, out of the blue | weak signal or low battery |

No buzz for distance, a station step or the start of following. The distance-warning buzz is gone.

**Second VESC in the logs.** Log level 4 now records both VESCs.

## Changed defaults

| Setting | Board | New default |
|---|---|---|
| `fm_display_mode` | remote | **2** — numbers show metres to the buggy (was 1, your speed) |
| `fm_warn_distance_m` | remote | 150 m, now only the bar's full scale (no buzz) |
| `fm_return_mode` | buggy | **1** — auto-return on |
| Setup wizard battery | — | 12S |

Boards with a stored value keep it; defaults apply to new or reset boards. The
[setup wizard](https://monterman.github.io/BREmote-V2/setup-wizard.html) gives you a full config
for your setup. Review it before you ride.

## Safety rules behind all of this

Manual always wins. "St" is the one not-working signal. The screen shows only what the buggy
confirms. Auto-return waits for the rider, and "waiting" means it will work. Arrival keeps the
throttle capped until one full release. Details in the
[Follow-Me guide](FOLLOW_ME_GUIDE.md#2-safety-philosophy).

## Thanks

Ludwig, BREmote's author ([lbre.de/BREmote](https://lbre.de/BREmote/),
[setup video](https://youtu.be/r6JIZEq3aTU), [github.com/Luddi96/BREmote-V2](https://github.com/Luddi96/BREmote-V2)),
and Heiguga for the Follow-Me ideas and the front stations.

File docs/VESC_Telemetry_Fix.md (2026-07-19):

# VESC Telemetry Fix — Analysis & Implementation Plan

**BREmote V2.5-Evo | RX firmware | Filed: 2026-05-09**
**Status: RESOLVED. The definitive "telemetry appears dead" root cause was a diagnostic bug — see 2026-07-19 section below. The SW51–SW55 fixes and the USB-C hardware constraint (below that) remain valid.**

---

## 2026-07-19 — Definitive Root Cause: the `?vescraw` Diagnostic Was Lying

The "VESC telemetry is dead / no telemetry" symptom that drove months of investigation
was, in the end, a **diagnostic false negative — not a hardware, cable, MUX, config, or
firmware fault.** Two independent bugs were found and fixed; neither was in the real
telemetry path.

### Bug 1 (the headline) — `?vescraw` hardcoded the wrong CRC

`?vescraw` builds a `COMM_GET_VALUES` probe by hand and hardcoded the CRC16 as `0x4007`.
The correct value is **`0x4084`** — CRC16-CCITT/XMODEM (poly `0x1021`, init 0) computed
over the single-byte payload `{0x04}`.

A VESC **silently discards any packet whose CRC does not match** — it does not NAK, does
not reply at any baud, it just drops the frame. So the malformed probe produced zero bytes
back **every time, against a perfectly healthy VESC**. `?vescraw` dutifully reported
"NO BYTES", which read as "the VESC is dead" — a **false negative that masked good
hardware** and sent the diagnosis chasing the VESC, the RX, the AW9523 MUX, the cabling,
the config, and firmware 6.06, none of which were ever at fault.

**Bench proof (FTDI, direct to VESC):** the corrected frame

```
02 01 04 40 84 03
```

returns a full `GET_VALUES` reply on **both VESC FW 6.05 and FW 6.06** — live 39.5 V /
26.7 °C. Wrong CRC → silence; correct CRC → full telemetry, on the same hardware, same
cable, same session.

**Fix:** `System.ino` `?vescraw` now emits `0x4084` and returns the real reply
(commit `492d672`).

**The production telemetry path was never affected.** The real path
(`getValuesSelective` → `sendToVESC` → `vesc_crc16`, table-driven CRC in `vesc_crc.cpp`)
always computed the CRC correctly. Only the hand-rolled `?vescraw` diagnostic frame carried
the wrong constant, which is exactly why live gauges (BLE, TX display) worked while the
diagnostic insisted the link was dead.

### Bug 2 — in-ride telemetry frozen by a throttle-skip gate

Separately, a regression (the "D1" gate, introduced 2026-06-04) skipped the VESC poll
whenever `thr_received ≥ 25`. On a continuous-throttle vehicle (the tow buggy) that means
`getVescLoop()` never runs once you are on the trigger, so telemetry froze at the boot
`0xFF` default (dashes) for the entire ride. Reverted to the SW55 unconditional 2 Hz poll
(commit `d68ed07`). The MUX-EMI concern the gate was meant to address is already covered by
the read-back-verify inside `setUartMux()`, so the skip was redundant.

### Bottom line

Nothing was wrong with the VESC, the RX, the AW9523 MUX, the cables, the config, or
firmware 6.06. The "no telemetry" verdict came from a diagnostic that was itself broken.
The SW51–SW55 findings below (GPS MUX yield, `rcv_err` persistence, boot MUX state) were
real and are still fixed; the USB-C-on-GPIO-18/19 constraint below is still a genuine
hardware limitation to respect in the field. But the thing that made telemetry *look*
dead was the `?vescraw` CRC.

---

## SW51–SW55 Resolution — 2026-05-14

### Primary Root Cause (Field Discovery)

**USB-C serial cable on GPIO 18/19 completely silences VESC UART.**

The ESP32-C3 native USB peripheral's D− and D+ lines share GPIO 18 and GPIO 19 with Serial1 (the UART used for GPS and VESC via the hardware MUX). Any USB-C cable plugged into the HT-CT62 during field operation overrides Serial1, dropping all VESC UART traffic to zero.

**Operational fix:** Unplug the USB-C cable before field use. This is a hardware constraint of the ESP32-C3 — no firmware change can eliminate it.

---

### Code Defects Fixed in SW55

Three additional firmware defects were found and fixed as part of the investigation:

**1. GPS MUX never yielding**

`getGPSLoop()` and `configureGPS()` were switching the UART MUX to GPS (channel 1) but never returning it to VESC (channel 0) on exit. VESC was left waiting indefinitely on every GPS poll cycle.

Fix: `setUartMux(0)` added at the end of both `getGPSLoop()` and `configureGPS()`. GPS always has priority on the MUX; GPS always yields the bus back to VESC when done.

**2. `rcv_err` flag persistence bug**

`receiveFromVESC()` set `rcv_err = true` on any bad first byte but never cleared the flag within the 200 ms receive window. One stray byte in the UART buffer poisoned the entire receive attempt for that cycle.

Fix: `rcv_err` flag removed entirely from `receiveFromVESC()`. CRC handles frame validation — the flag was redundant and harmful.

**3. Boot MUX state undefined**

`configureGPS()` (called at boot) left the MUX on GPS channel (channel 1) at exit. The first VESC poll after boot could fail if the MUX was never switched back.

Fix: `configureGPS()` now ends with `setUartMux(0)`. Boot sequence starts with the MUX on the VESC channel.

---

### SW54 Revert (MUX Retry Loops)

SW51 and SW52 added retry loops that re-attempted failed `setUartMux()` I2C writes 3–5 times in rapid succession. Under field conditions, the rapid I2C writes caused AW9523 bus corruption, manifesting as GPS chars=0 and VESC zero-packet responses — the opposite of the intended fix.

SW54 reverted all MUX retry logic. Single `setUartMux()` calls are reliable when the bus is not stressed by rapid retries.

---

### Status of Original Findings After SW51–SW55

| Finding | Description | Status |
|---|---|---|
| 1 | `Serial1.flush()` drains TX not RX | Fixed — removed (2026-05-11) |
| 2 | GPS/VESC share single 1 Hz timer | Fixed — independent `vesc_loop_timer` (2Hz) and `gps_loop_timer` (rate=`gps_update_hz`) implemented in SW55; GPS and VESC no longer compete for the same 1Hz slot |
| 3 | `foil_speed` / `foil_power` not reset on timeout | Fixed — `foil_power` and `foil_motor_amps` added to timeout reset block (SW49/SW50) |
| 4 | `vesc_timeout_s` default 12 s too long | Default now configurable via SPIFFS; field-appropriate value to be set after water test |
| 5 | E7 wetness de-latch path missing | Still pending — requires log evidence from a session where E7 triggers |

---

## Context & Philosophy

This fix session targets VESC telemetry display flicker visible on the TX dot matrix
during active riding. Before any implementation, the standing safety rule applies:

> Manual throttle control and LoRa packet handling are ALWAYS higher priority than
> telemetry. A failed telemetry read is acceptable. A failed throttle stop or a
> delayed LoRa packet is not. Any fix that introduces scheduling jitter on Core 0
> (generatePWM / triggeredReceive) must be rejected regardless of telemetry benefit.

---

## Exact Execution Model (Pre-SW55 — Historical Reference)

> **Note:** This block shows the unfixed execution model as it existed before SW55. Findings 1–3 are now fixed. The independent timer structure in Finding 2 replaces the single `loop_timer` shown here.

```
Core 1 — Arduino loop task
  esp_task_wdt_reset()
  webCfgLoop()
  checkSerial()
  loggerLoop()
  if millis()-loop_timer > 1000:
    wetness check (every 10 iterations = every 10s)
    getGPSLoop()        ← Serial1 via MUX position 1, 0-300ms
    getVescLoop()       ← Serial1 via MUX position 0
      setUartMux(0)
      vTaskDelay(10ms)  ← blocks Core 1
      Serial1.flush()   ← WRONG: drains TX not RX
      sendToVESC()
      receiveFromVESC() ← 200ms blocking timeout

Core 0 — FreeRTOS tasks
  generatePWM     priority 10, every 10ms   ← THROTTLE/STEERING (safety critical)
  triggeredReceive priority 5, IRQ-driven   ← LoRa packets (safety critical)
  checkConnStatus  priority 2, 200ms        ← BIND LED
  loggerTask       priority 1, 1Hz          ← SPIFFS writes
```

**GPS and VESC share Serial1 through a hardware MUX (AW9523 GPIO). There is no
mutex protecting the MUX switch. Both are called sequentially inside the same
1000ms block on Core 1.**

---

## Findings — All Issues Identified

### Finding 1 — Wrong Serial1.flush() Call

**File:** `VESC.ino` → `getVescLoop()`
**Severity:** High — causes corrupted frame reads

`Serial1.flush()` on ESP32 drains the **TX** buffer, not RX. The intent was to
clear stale RX bytes from a previous failed response before sending a new request.
As written it does nothing useful. Stale bytes from a failed prior response remain
in the RX buffer and corrupt the next read's frame start byte detection, causing
`receiveFromVESC()` to return 0 (CRC NOK or "Message Error").

**Fix:** Replace with RX drain:

```cpp
// WRONG — drains TX output buffer, not incoming data
Serial1.flush();

// CORRECT — drains stale incoming bytes before new request
while (Serial1.available()) Serial1.read();
```

**Risk:** Zero. One line. No architectural change.

---

### Finding 2 — VESC Polled at 1Hz, GPS and VESC Share Time Budget

**File:** `V2_Integration_Rx.ino` → `loop()`
**Severity:** High — root cause of display flicker

Everything in the 1-second block runs sequentially. If GPS drains a burst of
sentences (satellite acquisition, 5Hz module output), VESC gets less of its
200ms window. Sequential coupling means a slow GPS drain directly delays VESC.

**Proposed Fix A (REJECTED): New FreeRTOS task for VESC**

- Requires MUX mutex — Serial1 shared, no protection exists
- Core 0 is already full (generatePWM p10, triggeredReceive p5, checkConnStatus p2)
- Any Core 1 task above loop priority delays WDT feed → panic risk
- A misbehaving VESC read (VESC fault, UART garbage) blocking 200ms in a task
  does not yield → WDT fires → full RX reboot → total control loss
- **VERDICT: Do not implement. Violates safety philosophy.**

**Proposed Fix B (ACCEPTED): Separate independent timers in loop()**

```cpp
// Two independent timestamps instead of one shared loop_timer:
static unsigned long vesc_timer = 0;
static unsigned long gps_timer  = 0;

if (millis() - vesc_timer > 500) {   // 2Hz — independent of GPS
    vesc_timer = millis();
    if (usrConf.data_src == 2) getVescLoop();
}
if (millis() - gps_timer > (1000 / max(1, (int)usrConf.gps_update_hz))) {
    gps_timer = millis();
    if (usrConf.gps_en) getGPSLoop();
}
```

- Stays entirely on Core 1. No new tasks. No new mutexes. No WDT changes.
- GPS and VESC no longer compete for the same time slot.
- If both timers fire in the same loop() iteration they still run sequentially
  (MUX switch handles bus isolation) — but this is already the case and is safe.
- The 10ms MUX settle delay still blocks Core 1 at 2Hz = 20ms/second. Acceptable.
- **VERDICT: Implement. Low risk. Highest practical benefit.**

---

### Finding 3 — stale foil_speed and foil_power Never Go N/A

**File:** `VESC.ino` → `getVescLoop()`
**Severity:** Medium — shows wrong values after VESC drops

When `millis() - last_uart_packet > vesc_timeout_s * 1000`, only `foil_bat` and
`foil_temp` are set to `0xFF`. `foil_speed` and `foil_power` are written only on
successful reads and never explicitly invalidated. After VESC drops, the display
continues showing the last-known speed and power indefinitely.

**Fix:** Add missing fields to the timeout block:

```cpp
if (millis() - last_uart_packet > ((unsigned long)usrConf.vesc_timeout_s * 1000UL)) {
    telemetry.foil_bat   = 0xFF;
    telemetry.foil_temp  = 0xFF;
    telemetry.foil_speed = 0xFF;  // ADD — was missing
    telemetry.foil_power = 0xFF;  // ADD — was missing
}
```

**Risk:** Zero. Two additional lines in existing block.

---

### Finding 4 — vesc_timeout_s Default Too High

**File:** `BREmote_V2_Rx.h` → `defaultConf`
**Severity:** Low-medium — stale data shown too long after drop

Current default: 12 seconds. A VESC that is truly connected responds within
200ms every time. 12 seconds means the display shows stale bat/temp for up to
12 seconds after connection drops.

**Critical constraint:** 3 seconds is too aggressive. VESCs under heavy
regenerative braking or in fault recovery can back up their UART for 1–3 seconds.
Setting timeout to 3s means N/A flashes during every legitimate VESC fault event,
alarming the rider during a moment requiring throttle focus.

**Recommended default:** 5–8 seconds. Suggest **6 seconds** as the new default —
fast enough to show stale clearly, slow enough to survive VESC fault transients.

**Fix:** In `defaultConf` initialization:

```cpp
6,   // vesc_timeout_s: was 12; 6s balances responsiveness vs fault tolerance
```

**Risk:** Zero. One value change. User can override via web UI.

---

### Finding 5 — E7 Wetness Latch: De-Latch Path Missing

**Filed from:** the build workflow session + field test observation
**Severity:** High — survives TX power cycle, only clears on RX reboot

**Symptom:** E7 (water ingress) error displays on TX and is latched on RX.
Power cycling TX alone does not clear it. Only RX power cycle clears it.

**Hypothesis — VESC Stale Struct as False Trigger:**
`checkWetness()` reads a hardware sensor via AW9523. However, the wetness
detection path likely reads from a field that could momentarily read garbage
during a VESC UART collision or MUX switch event. If the wetness sensor share
the AW9523 I2C bus with the MUX control lines, a MUX switch during a VESC read
could corrupt an AW9523 read, returning a false wet state. One false wet reading
sets the latch. The latch has no clear path in the runtime code — it would need
an explicit `remote_error &= ~E7_MASK` somewhere that doesn't appear to exist.

**Diagnostic:** Upload logs from a session where E7 appears. Look for:

- VESC dropout events (duty_cycle going to 0, then telemetry going stale)
- Timestamp correlation with E7 onset
- Whether E7 always follows a VESC miss within 1–2 loop iterations

**Fix approach (not yet implemented — needs log confirmation first):**

1. Add explicit de-latch: after N seconds of clean wetness reads, clear E7 flag
2. Guard `checkWetness()` to only run when MUX is NOT in mid-switch state
3. Add wetness column to log output for cross-correlation

**This is filed for a dedicated fix session after log confirmation.**

---

## Implementation Order for the build workflow

| Priority | Finding | Files | Risk | Lines |
| --- | --- | --- | --- | --- |
| 1 | Serial1.flush() → RX drain | VESC.ino | Zero | 1 |
| 2 | foil_speed/power → 0xFF on timeout | VESC.ino | Zero | 2 |
| 3 | Separate GPS/VESC timers in loop() | V2_Integration_Rx.ino | Low | ~10 |
| 4 | vesc_timeout_s default 12→6 | BREmote_V2_Rx.h | Zero | 1 |
| 5 | E7 de-latch path | System.ino | Medium | TBD after log analysis |

**Findings 1–4 are safe to bundle into one the build workflow session.**
**Finding 5 (E7) needs log evidence first — file separately.**

---

## What This Does NOT Fix

- The telemetry rotation index mismatch (7 fields cycling at 10Hz, VESC updating
  at 2Hz after fix) — the display will still show slightly stale values between
  VESC polls. This is acceptable and not worth the complexity of synchronizing the
  rotation index to VESC update events.
- The fundamental 200ms receive timeout in receiveFromVESC() — this is appropriate
  for the baud rate and should not be reduced without VESC hardware profiling.
- Any telemetry issues caused by a second VESC on CAN — CAN telemetry requires
  a separate implementation path and is out of scope for this fix.

---

## Second VESC / CAN Note

Testing with VESC2 will confirm UART protocol compatibility but will NOT fix the
display flicker — all issues above are firmware-side, not VESC-hardware specific.
When CAN is added for VESC2, the telemetry struct and timeout logic will need to
be extended to handle two VESC sources. File that as a separate feature when ready.

---

## Blocking Priority Reminder

**Bug 1 (motor running during RTM arm window) takes absolute priority over this
entire document.** This VESC fix session does not begin until Bug 1 is confirmed
fixed, compiled, and field-tested. The arm ceremony throttle blackout fix is 4
targeted lines in TX RTMState.ino and is ready to implement on approval.

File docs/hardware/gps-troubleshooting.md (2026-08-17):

# TX GPS — Wiring & Troubleshooting Guide

**Who this is for:** First-time builders connecting a GPS module to the BREmote TX unit.  
**When to use it:** GPS dot on TX display blinks slowly and never goes solid, or you are wiring the GPS for the first time before potting.

---

## **What you need**

- BREmote TX unit powered on via USB  
- Arduino IDE with Serial Monitor open at **115200 baud**  
- GPS module (BN-220 recommended)  
- 4 small wires

---

## **Step 1 — Wire the GPS module**

You need **4 wires** between the ESP32-C3 board and the GPS module.

**This section is the TX board** (BN-220 on `Serial1`). For the RX, see the
[BN-880 → RX wiring guide](../GPS_Wiring_BN880_RX.md) — the RX has a UART mux and different pin roles.

| Wire color | On the TX board | To BN-220 |
| :---- | :---- | :---- |
| 🔴 Red | **3.3V** | **VCC** |
| 🟡 Yellow | **G18** — the TX's **receive** pin (`P_U1_RX`) | **GPS TX** |
| ⬜ White | **G19** — the TX's **transmit** pin (`P_U1_TX`) | **GPS RX** |
| ⬛ Black | **GND** | **GND** |

> ⚠️ **TX and RX are NOT the same — the pin roles are inverted between the two boards:**
>
> | Board | GPIO 18 | GPIO 19 |
> |---|---|---|
> | **TX** | `P_U1_RX` — receive | `P_U1_TX` — transmit |
> | **RX** | `P_U1_TX` — transmit | `P_U1_RX` — receive |
>
> Read from `BREmote_V2_Tx.h:758-759` and `BREmote_V2_Rx.h:1142-1143`. **The comment above the TX
> defines says the assignment matches the RX — it does not.** Do not carry an RX pinout over to a TX.

### Which way do the wires go?

**On the RX, nothing crosses** — wire label to label. That is proven from the board files: the RX pad
silkscreened `RX` is driven by the board's transmitter, because the crossover is routed on the PCB.
See the [BN-880 → RX wiring guide](../GPS_Wiring_BN880_RX.md) for the full trace.

**On the TX this has not been verified.** There is no mux to trace, and the repo does not settle
whether the TX's board artwork pre-crosses the UART the way the RX's does. So **test it — it takes
two minutes and cannot damage anything** (both ends are 3.3 V logic):

1. Wire it, power up, run **`?gpsbaud`** — a listen-only scan that reports whether any bytes arrive.
   It needs no fix and no sky, so it answers the wiring question by itself.
2. **Bytes at some baud → correct.** Confirm outdoors with `?printgps`.
3. **Nothing at any baud →** swap the two data wires and run `?gpsbaud` again.

Whichever returns bytes is right for your board. If you settle it either way, please open an issue —
it closes this gap for everyone.

---

## **Step 2 — Check the GPS LEDs before testing software**

Before opening the Serial Monitor, look at the GPS module LEDs:

| LED | What you see | What it means |
| :---- | :---- | :---- |
| Blue | Blinking | ✅ GPS is powered and sending data |
| Blue | Off | ❌ GPS has no power — check VCC and GND wires |
| Red | Off | GPS searching for satellites — normal indoors |
| Red | Blinking | ✅ GPS has a fix — satellites locked |

**If blue LED is off → fix power wiring first before proceeding.**

---

## **Step 3 — Open Serial Monitor and exit the charge screen**

1. Connect TX to your computer via USB  
2. In Arduino IDE: **Tools → Serial Monitor**  
3. Set baud rate to **115200** (bottom-right of Serial Monitor)  
4. You will see the TX boot messages

If the TX shows a charging screen, type this command and press Enter:

?exitchg

**Expected output after `?exitchg`:**

Starting Radio... Power: 20 Region: US/AU915 TOA: 7488 Done

Web config AP started. SSID: BREmoteV2-TX-WebConfig

IP: 192.168.4.1

TX GPS \[BN-220\]: connecting at 9600...

TX GPS \[BN-220\]: init complete (115200, 5Hz, NMEA filtered)

If you do **not** see the GPS init lines, type:

?gpsreinit

**Expected output after `?gpsreinit`:**

Re-running initTxGPS()...

TX GPS \[BN-220\]: connecting at 9600...

TX GPS \[BN-220\]: init complete (115200, 5Hz, NMEA filtered)

tx\_gps\_initialized after reinit: YES

Run ?gpsraw to check Serial1 output.

---

## **Step 4 — Check GPS status with ``?printgps`**

Type this command and press Enter:

?printgps

**Expected output — everything working correctly:**

\----- TX GPS Status \-----

gps\_en:             1

gps\_chip\_type:      0

speed\_src:          5

tx\_gps\_initialized: YES

Serial1 available:  412

Chars processed:    44261

Sentences failed:   0

Location valid:     YES

Location age (ms):  14

Latitude:           41.936492

Longitude:          \-87.678212

Speed valid:        YES

Satellites:         12

HDOP:               75

tx\_gps\_speed:       0

\-------------------------

**What each field means:**

| Field | Good value | Problem value | What to do |
| :---- | :---- | :---- | :---- |
| `tx_gps_initialized` | `YES` | `NO` | Type `?gpsreinit` |
| `Serial1 available` | \> 0 | `0` | GPS not sending — see Step 5 |
| `Chars processed` | Increasing | Always `0` | GPS data not reaching ESP32 — see Step 5 |
| `Sentences failed` | `0` | \> 0 | Baud rate wrong — check `gps_chip_type` in web config |
| `Location valid` | `YES` | `NO` | Go outdoors and wait up to 2 minutes |
| `Satellites` | 8 or more | `invalid` or \< 4 | Go outdoors — indoors gets poor signal |

---

## **Step 5 — Check raw GPS data with `?gpsraw`**

If `Serial1 available` was `0` or `Chars processed` was `0`, type:

?gpsraw 10

This listens on the GPS wire for 10 seconds and prints everything it receives.

---

**✅ Good — wiring correct, GPS working:**

\--- Raw GPS bytes from Serial1 (10 seconds, type q to quit) \---

$GNRMC,212045.80,A,4156.19047,N,08740.68690,W,0.231,,240426,,,A\*75

$GNGGA,212045.80,4156.19047,N,08740.68690,W,1,11,1.08,195.1,M,-33.8,M,,\*7F

$GNGSA,A,3,29,05,20,15,21,18,23,26,,,,,1.88,1.08,1.54\*13

$GNRMC,212046.00,A,4156.19047,N,08740.68686,W,0.266,,240426,,,A\*7B

\--- End raw GPS dump \---

You can read clear text starting with `$`. GPS is alive and talking. Continue to Step 6\.

---

**❌ Problem — wires swapped or broken:**

\--- Raw GPS bytes from Serial1 (10 seconds, type q to quit) \---

\--- End raw GPS dump \---

Completely empty — nothing received at all.

**Fix:** Double check all 4 wires match the table in Step 1\. GPIO19→GPS TX, GPIO18→GPS RX. Then run `?gpsreinit` and `?gpsraw 10` again.

---

**❌ Problem — baud rate mismatch:**

\--- Raw GPS bytes from Serial1 (10 seconds, type q to quit) \---

▒b\\▒▒▒▒▒▒▒▒▒▒▒▒▒▒▒▒▒▒ N▒▒▒{▒b\\▒▒▒▒▒▒▒▒▒▒▒

\--- End raw GPS dump \---

Garbage symbols — GPS is sending but at a different speed.

**Fix:** Go to web config at `http://192.168.4.1` (connect to WiFi `BREmoteV2-TX-WebConfig`). Set `gps_chip_type`:

- BN-220 → `0`  
- HGLRC M100 Micro (M10 chip) → `2`

Save, reboot, test again.

---

**❌ Problem — GPS not powered:**

Same as broken wire — empty output. Check: is the **blue LED blinking**? If not, the VCC or GND wire is missing or loose.

---

## **Step 6 — Get a GPS fix outdoors**

Once `?gpsraw` shows clean sentences, the wiring is correct. Now get a satellite fix:

1. Take the TX unit **outside** with a clear view of the sky  
2. Wait up to **2 minutes** for the first fix  
3. The **red LED** on the GPS will start blinking when satellites are locked  
4. Run `?printgps` — you should see `Location valid: YES` with real coordinates

**Verify:** Compare the coordinates in `?printgps` against a GPS app on your phone. They should match within about 5 meters.

---

## **Step 7 — Pre-potting checklist**

**Do not seal the unit until every item is ticked:**

- [ ] Blue LED on GPS is blinking  
- [ ] Red LED on GPS is blinking  
- [ ] `?printgps` shows `tx_gps_initialized: YES`  
- [ ] `?printgps` shows `Serial1 available` \> 0  
- [ ] `?gpsraw 10` shows readable `$GNRMC` sentences  
- [ ] `?printgps` shows `Location valid: YES`  
- [ ] Latitude and longitude match your phone within 5 meters  
- [ ] `Sentences failed: 0`
- [ ] GPS dot on TX display is **slow blinking** (acquiring fix — `gps_en=1` and correct `gps_chip_type` set)
- [ ] After outdoor fix: GPS dot goes **solid** — confirms GPS signal will show through potting

  > **Why this matters:** Once the GPS is potted you cannot see the blue/red LEDs inside. After potting, the TX display GPS dot (C7 R0) is your only real-time indicator. Slow blink = no fix; solid = locked. GPS dot only appears when `gps_en = 1` in SPIFFS and `gps_chip_type` is set to match the installed module.

---

## **Common failures at a glance**

| Symptom | Most likely cause | Fix |
| :---- | :---- | :---- |
| GPS dot blinks slowly forever | No satellite fix | Go outdoors, wait 2 minutes |
| `Serial1 available: 0` | Wrong wiring or broken wire | Check Step 1 wiring table |
| `Sentences failed` \> 0 | Wrong `gps_chip_type` | Set `0` for BN-220 in web config |
| `tx_gps_initialized: NO` | Charge screen blocking boot | Type `?exitchg` first |
| Blue LED off | No power to GPS | Check VCC and GND wires |
| Garbled `?gpsraw` output | Baud rate mismatch | Change `gps_chip_type` in web config |
| Nothing at all, but the module works on a drone | Module left **UBX-only** by Betaflight — NMEA output disabled | On the RX: flash current firmware, run `?gpssetup` — [see below](#-the-other-my-gps-shows-nothing-at-all-a-module-that-came-off-a-drone) |
| Worked before potting, dead after | Wire broken inside compound | Open unit, retest with `?gpsraw 10` |

---

## **Potting tips**

1. **Test fully before potting** — once sealed you cannot see the GPS LED  
2. **Leave a small loop of wire** at each solder joint — prevents tension pulling joints loose during pour  
3. **Use low-viscosity compound** around the GPS module — thick epoxy can stress PCB as it shrinks  
4. **Do not pot in cold temperatures** — compound cures slowly below 15°C  
5. **Test again immediately after curing** — before final assembly

---

## **Supported GPS modules**

| Module | Voltage | Works on TX? | Notes |
|---|---|---|---|
| **BN-220** | 3.3V | ✅ Confirmed | Recommended for TX. Set `gps_chip_type=0` |
| **BN-880** | **5V** | ❌ No | **The RX module** — the only one in this table with a compass, which RTM and Follow-Me need. Set `gps_chip_type=1`. Take 5 V from the VESC and put the UART header's selector on `5V`; the TX supplies 3.3 V only, so this is not a TX option. [Wiring guide →](../GPS_Wiring_BN880_RX.md) |
| **[HGLRC M100 Micro](https://www.hglrc.com/products/hglrc-m100_mini-gps)** | 3.3–5V | ⚠️ **Untested** | M10 chip, no compass. Set `gps_chip_type=2`. 🚨 **Do not assume this works yet.** The M10 removed the legacy UBX config messages, so the TX cannot change its baud (`CFG-PRT` does not exist on M10 — see [u-blox M10 SPG 5.10 interface description](https://content.u-blox.com/sites/default/files/u-blox-M10-SPG-5.10_InterfaceDescription_UBX-21035062.pdf) §3.10). If the module does not already ship at 115200 the TX will open the UART at the wrong speed and show **no NMEA at all**. Also note 9600 cannot physically carry 10 Hz (GGA+RMC ≈ 1400 B/s ≈ 14000 baud needed) — 38400 minimum. Verify with `?gpsbaud` before trusting this row. |
| [HGLRC M100 Pro](https://www.hglrc.com/products/m100-pro-gps) | 3.6–5.5V | ❌ No | Needs >3.3V — UART corrupted at ESP32-C3 3.3V supply |
| M101Q / M10Q | 5V | ❌ No | Needs 5V — TX only provides 3.3V |

---

---

# GPS configuration — how it works, and how to fix it (V2.5-Evo, 2026-07-30)

> **Read this section first if the GPS "stops working" for no obvious reason.**
> Everything here is recoverable. Nothing requires re-flashing.

## Installing a NEW GPS module on the TX

Plug it in and power on. That is the whole procedure — the firmware finds the module wherever
it is and configures it. Then confirm:

```
?gpscfg
```

You want to see `dynModel : 5 (Sea)`. If you do, you are done.

**Optional but recommended once per remote** — make the settings permanent inside the module
so boot only has to verify them rather than re-apply them:

```
?gpssetup
```

This finds the module, raises it to 115200, applies every setting with the acknowledgement
checked, writes the result to the **module's own flash**, and reads it back to prove it.
Run it once on the bench when you assemble a remote or swap a GPS. Takes ~15 s.

> The baud is stored **in the GPS module**, not in the TX config. That is deliberate: adding a
> field to the TX config struct would force a `SW_VERSION` bump, which **wipes TX SPIFFS** —
> pairing, calibration, every setting. The module has its own non-volatile memory, so the
> setting lives there for free and follows the module if you move it to another remote.

## What the firmware does at boot

1. **Listens** for NMEA across 115200 / 38400 / 9600 / 57600 / 19200. It transmits nothing
   while the baud is unknown — see the warning below for why that matters.
2. If the module is heard below 115200, moves it up **at the module's own baud**, so the
   command is understood rather than sprayed at a guess.
3. Detects which configuration dialect the module speaks — legacy `UBX-CFG` (u-blox 6/7/8) or
   `CFG-VALSET` (u-blox M9/M10) — by sending `CFG-NAV5` and reading the answer.
4. Applies `dynModel=Sea`, silences GSV/GLL/VTG, then sets the measurement rate — **in that
   order**, because silencing the chatter first makes every later acknowledgement arrive
   promptly.
5. **Checks the acknowledgement on every single write** and prints the result:

```
TX GPS [BN-220]: heard the module at 115200 — skipping the dual-baud dance
TX GPS config [legacy CFG (u-blox 6/7/8)]: dynModel=Sea OK | rate=200ms OK | GLL OK | GSV OK | VTG OK
```

Nothing here can block boot or disable the GPS. If a module is unfamiliar or silent, the
settings are sent anyway and the outcome is **reported**, not enforced.

## 🚨 The one failure worth knowing: "UART RX disabled"

**Symptom.** The GPS still streams position, but every configuration write fails:

```
TX GPS config [UNVERIFIED - module sends no ACK]: dynModel=Sea no-ACK | rate no-ACK | GLL no-ACK ...
```

and `?gpsbaud` shows the signature — **NMEA present, UBX dead**:

```
  baud     NMEA
  9600     yes
  -> UBX input: DEAD — module is NOT accepting UBX
```

**Cause.** u-blox counts UART framing errors. Past roughly **100**, the module **switches off
its own receiver** and ignores all input until it loses power. Framing errors come from
sending data at a baud the module is not using.

**Critical detail:** the error count does **not** reset when the ESP32 reboots. It resets only
when the **GPS module loses power**. So a bench session of reflashes and reboots can
accumulate errors across many boots and trip it mid-session.

### ✅ Recovery — 10 seconds, no reflash

**Unplug USB, then flip the power switch off. Wait a couple of seconds. Power back on.**

That is the entire fix, and the order matters:

- **Unplugging USB cuts power fully** on both the TX and the RX (owner-confirmed 2026-07-30).
- On the TX, **flipping the switch off as well** guarantees the remote — and therefore the GPS
  module hanging off it — is completely dead rather than running on the internal cell.
- On the RX, unplugging USB is sufficient.

A reboot, an ESP32 reset, or a re-flash will **not** clear it. The GPS module has to actually
lose power. That is also why this cannot be fixed over the wire: the module has stopped
listening, so no command can reach it.

Then confirm:

```
?gpsbaud     ->  should read "UBX input: alive"
?gpscfg      ->  should read "dynModel : 5 (Sea)"
```

If `?gpsbaud` still reports UBX dead after a full power cycle, the problem is not this — check
wiring and the module's supply rail (5 V for a BN-880, 3.3 V for a BN-220).

**On the RX, also confirm you are on the right connector.** The two UART headers are one hardware
UART shared by a 74HC4052 mux: **`UART 1.0` is the VESC channel, `UART 1.1` is the GPS channel**
(`setUartMux()` in `System.ino` — channel 0 = VESC, channel 1 = GPS). A GPS wired into `UART 1.0` is
switched away from the UART and reports exactly this symptom — dead at every baud — with perfectly
correct wiring.

### How the current firmware avoids causing it

- Baud detection is **listen-only**. It never transmits at an unconfirmed baud.
- The dual-baud "dance" — which does transmit blind — now runs **only as a last resort**, when
  listening hears nothing at all. On a working module it is skipped entirely, so a normal boot
  produces **zero** wrong-baud bytes.
- `?gpsbaud` scans by listening, and checks UBX **once**, at the baud that answered.

## 🚁 The other "my GPS shows nothing at all": a module that came off a drone

**Symptom.** A module that looks completely dead. No NMEA at any baud, `?gpsraw` empty,
`Chars processed: 0`, GPS dot never leaves slow-blink — but the blue LED is blinking, the wiring
checks out, and the module works fine on a flight controller.

**Cause: it is not dead, it is speaking the wrong protocol.** Betaflight's GPS auto-config switches
u-blox modules to **UBX only and turns NMEA output off**, and saves that into the module's
battery-backed memory and flash — so it survives every power cycle. This firmware parses NMEA and
nothing else, so it sees an empty wire. **Most modules sold as an "M10 GPS" are aimed at the drone
market**, so a brand-new one can arrive in this state too, not just a second-hand one.

**Recovery on the RX — two steps, no PC tooling:**

1. Flash the **current RX firmware**.
2. Run **`?gpssetup`**.

That is the whole procedure. The RX's listen-only baud scan now recognises a **complete,
checksum-valid UBX frame** as evidence of life, not just `$G…`, so a UBX-only module is detected at
its real baud instead of being written off as "no module". Having found it, the firmware re-enables
NMEA output on UART1 — the GGA and RMC message rates plus the port's NMEA output protocol — and
`?gpssetup` writes that into the module's own flash so it sticks. Boot alone applies the same repair
to RAM, so you get NMEA back immediately; `?gpssetup` is what makes it permanent.

You will see it happen on serial:

```
GPS: !! module is ALIVE at 115200 baud but speaking UBX ONLY — no NMEA at all.
GPS: !! That is the signature of a flight-controller setup: Betaflight puts
GPS: !! u-blox in UBX-only mode and saves it to battery-backed RAM and flash,
GPS: !! so it survives every power cycle. This firmware parses NMEA, so until
GPS: !! NMEA output is switched back on it sees an empty wire.
GPS: !! re-enabling NMEA output below — see the config report.
...
GPS NMEA output on UART1 (persisted): GGA OK/valset | RMC OK/valset | UBX-out OK/valset | NMEA-out OK/valset
GPS: NMEA output re-enabled on UART1 — GGA and RMC are the two sentences this firmware parses.
```

`?gpsbaud` also reports the diagnosis on its own — it prints `UBX only` in the protocol column and
writes nothing.

**Caveats worth knowing:**

- The automatic repair uses the **`CFG-VALSET` (u-blox M9/M10)** interface, which is what a
  drone-market module is. A legacy u-blox 6/7/8 gets its protocol mask rewritten when the firmware
  moves it to 115200.
- **It is reported, never enforced.** If the module refuses the writes the firmware says so — look
  for `REJECTED` in the line above — and carries on rather than failing boot. That is the one case
  left that still needs u-center on a PC.
- This is the **RX**. The TX firmware does not yet carry the repair.
- Before this firmware, this failure was indistinguishable from dead hardware and needed u-center
  to fix. If you gave up on a module for this reason, it is probably fine — try it again.

## GPS serial commands

| Command | What it does | Blocks |
|---|---|---|
| `?gpscfg` | Reads `dynModel` back **out of the module** — proves what it is actually running, not what we asked for | ~3 s |
| `?gpsbaud` | Listen-only scan; reports which baud has NMEA and whether UBX input is alive | ~2 s |
| `?gpsbaud <rate>` | Moves **our UART only**, module untouched. Reverts on reboot | <1 s |
| `?gpsbaud set <rate>` | Moves **the module** and writes it to the module's flash | ~6 s |
| `?gpssetup` | **One-time full setup**: find, raise to 115200, configure, save permanently, verify | ~15 s |
| `?gpsraw [sec]` | Dumps raw NMEA — use when nothing else responds | 5 s |
| `?gpsreinit` | Re-runs GPS init without rebooting | ~2 s |
| `?gpscoldreset` | Clears the module's satellite cache; forces fresh acquisition | instant |

All of these are **USB only** — the TX disables its serial port on a normal battery boot.
They block the main loop (display, RTM/FM), so they are **bench commands**. Type `quit` to
abort a long one. They do **not** stall the LoRa link or trip the RX failsafe.

## Baud vs update rate — why 9600 is not enough

At 8N1 each byte costs 10 bits. GGA + RMC is roughly 142 bytes per fix:

| Rate | Needs | 9600 gives | 115200 gives |
|---|---|---|---|
| 1 Hz | ~1,420 bit/s | ✅ 15 % | ✅ 1 % |
| 5 Hz | ~7,100 bit/s | ⚠️ **74 %** — no headroom, drops sentences | ✅ 6 % |
| 10 Hz | ~14,200 bit/s | ❌ **impossible** | ✅ 12 % |

The firmware warns at boot if the configured rate does not fit the link:

```
TX GPS: !! 9600 baud is only 27% clear of what 5 Hz needs — sentences WILL drop.
        Run '?gpssetup' to move the module to 115200 permanently.
```

## u-blox M10 modules (HGLRC M100 Micro and similar)

M10 **removed** the legacy configuration messages. Its entire `UBX-CFG` class is `CFG-CFG`,
`CFG-RST`, `CFG-VALDEL`, `CFG-VALGET`, `CFG-VALSET` — `CFG-PRT`, `CFG-MSG`, `CFG-RATE`,
`CFG-NAV5` and `CFG-GNSS` do not exist and are rejected.

The firmware handles this automatically: a rejection means "wrong dialect", not "bad
hardware", so it re-sends the same setting through `CFG-VALSET`. You do not need to declare
which chip you fitted. A BN-220, BN-880, NEO-M8N, NEO-M9N or MAX-M10S all self-configure from
the same firmware image.

## **Serial commands quick reference**

| Command | What it does |
| :---- | :---- |
| `?exitchg` | Exit the charge screen so boot completes |
| `?printgps` | Full GPS status snapshot |
| `?gpsraw 10` | Dump raw GPS bytes for 10 seconds |
| `?gpsreinit` | Re-run GPS initialization without rebooting |

---

## ⭐ Dynamic platform model — `dynModel` (2026-07-28, updated 2026-08-16)

**Every u-blox module ships in `dynModel 0` (Portable)**, which permits the receiver's own navigation filter to accept solutions up to **310 m/s horizontal and 50 m/s vertical** — because a "portable" device might be aboard an aircraft. Nothing in this project leaves the surface of a lake.

**That permissiveness has a measured cost.** The foilIQ logger — same u-blox family, same buggy — emitted **bogus 254 km/h speeds and 4800 m altitudes as HIGH-confidence fixes (5–7 satellites, HDOP < 3)** on 2026-07-24, one day before a session where FM veered and RTM would not arm.

On the RX such readings feed `gpsPhaseACheck()`, which increments `gps_suspect_count` and at threshold sets **`gps_rejected` — and that blocks RTM arming.** Killing the solutions inside the receiver is far better than filtering them downstream.

`dynModel 5 (Sea)` constrains the filter to ~25 m/s horizontal and ~0 m/s vertical and pins altitude near the surface. Removing the vertical degree of freedom also sharpens the horizontal solution — and **course-over-ground is derived from horizontal velocity**, which is exactly what FM steers on.

**Applied to:** BREmote RX (all `gps_chip_type`), BREmote TX (types 0 and 2), foilIQ WaveShare.
**Re-sent on every boot** by `configureGPS()` / `initTxGPS()`, so it survives a backup-battery death, a module swap, or a factory reset. `?gpssetup` additionally writes it into the module's own flash.

**Payload:** u-blox defaults with only `dynModel` altered, `mask = 0x0001`.

### ⚠️ 500 m altitude ceiling — and how to change the model

**`dynModel = Sea` is valid to 500 m.** The Great Lakes sit at 75–183 m (Michigan 176 m), roughly 3× margin. **On a lake above roughly 500 m the RX should be moved to Automotive** — 6,000 m ceiling, 100 m/s horizontal, 15 m/s vertical — or good fixes start being rejected. Automotive is still far tighter than Portable and still kills the 254 km/h class of garbage.

**On the RX this is a config field — `gps_dyn_model`. No editing source, no recompiling:**

```
?set gps_dyn_model 4
?save
```

Reboot. The boot log then reads `dynModel=Automotive` instead of `dynModel=Sea`, and `?gpscfg` reads `dynModel : 4` back **out of the module**. The same field is on the RX web page and in the Web Serial Config Tool as **GPS Dynamic Model**.

**Two numbering systems here — do not mix them up.** What you type is the *config value*; what the module reports back is the *u-blox dynModel*:

| `gps_dyn_model` — what you set | u-blox `dynModel` — what the module reports | Model |
|---|---|---|
| **0** *(default)* | 5 | **Sea** — leave it here below 500 m |
| **4** | 4 | **Automotive** — for riders above ~500 m |
| **5** | 5 | Sea, stated explicitly |

Anything that is not an explicit `4` resolves to Sea, so a corrupt or out-of-range value fails toward the conservative model — never back to Portable. Portable is deliberately not offered at all.

> **The TX has no such field.** Its `dynModel` is still fixed at Sea inside `setNav5Sea` in `Source/V2_Integration_Tx/GPS.ino`, and changing it there does mean recompiling. That only affects the speed the TX logs and displays — the autonomous modes steer on the **RX** GPS, which is the one with the setting.

### NMEA sentence filter — GSV / GLL / VTG disabled

**TinyGPS++ parses only GGA and RMC.** `GSV`, `GLL` and `VTG` are clocked across the wire, buffered, parsed to a dead end and discarded. GSV is the worst — with multiple constellations it is 6–10 sentences per epoch alone.

On the **RX** that waste is not free: Serial1 is time-shared with the VESC through the 74HC4052 mux, so the GPS competes for both the line and the 2048-byte ring — the exact resource whose scarcity caused the STAGE 1 starvation. **The TX has shipped this identical filter since 2026-06-05**, recorded there as resolving *"Audit #5, GPS chatter choking the link."* The RX only received it on 2026-07-28.

**Verify with `?diag`:** `g_diag_gps_bytes` should fall sharply while `g_diag_gps_sent_per_s` (complete *parsed* sentences) holds steady.

### ✅ Confirming it actually took — `?gpscfg`

The firmware checks the module's ACK on every configuration write, but an ACK only proves the module *accepted* the write — not that the setting survived a later write or a warm restart. `?gpscfg` is the second, independent check: it **polls the module** and prints what it reports:

```
----- GPS live config (polled from the module) -----
  dialect  : legacy UBX-CFG (u-blox 6/7/8)
  dynModel : 5  (Sea)  <-- matches gps_dyn_model
  fixMode  : 3  (1=2D 2=3D 3=auto)
  GSV      : disabled (good)   rates: 0 0 0 0 0 0
  chip_type: 1 (0=BN-220 1=BN-880 2/3=M10)
```

Bounded at ~3 s, safe on the bench. The verdict on the `dynModel` line is compared against **your `gps_dyn_model` setting**, so an Automotive board reads `dynModel : 4 <-- matches gps_dyn_model`. **`<-- FACTORY DEFAULT, the write did NOT take` or `GSV : STILL ENABLED` means the write was silently rejected** — wrong checksum, unsupported on that chip, or the module still at the old baud. Also available from the web-UI quick-commands dropdown.

---

## RX Compass — Wiring Verification and Serial Commands

**Who this is for:** Builders connecting a magnetometer (or a GPS module with one built in) to the BREmote RX unit.
**When to use it:** Compass not detected at boot, RTM steering unreliable, or before potting the RX unit.

### Compass I2C Wiring (RX ESP32-C3)

The compass connects via I2C. Both the BN-880 and the HGLRC M100-5883 have one built in — with either, the GPS and compass share one cable.

> **Two different magnetometers are supported, and the RX works out which one is fitted at boot:**
>
> | I²C address | Part | Found on |
> |---|---|---|
> | `0x0D` | **QMC5883L** | Beitian BN-880, HGLRC M100 Pro |
> | `0x2C` | **QMC5883P** | HGLRC M100-5883 |
> | `0x1E` | HMC5883L | very old BN-880 stock — **reported, not supported** |
>
> These are **different silicon, not a revision** — among other things their data registers start at a
> different address — so the RX probes for both and drives whichever it finds with the right driver.
> One firmware image, either module; nothing to set. The boot log names the part it is driving.

| RX ESP32-C3 Pin | Compass / BN-880 | Signal |
|---|---|---|
| **GPIO 2** | SDA | I2C Data |
| **GPIO 1** | SCL | I2C Clock |
| `V+` on **`UART 1.1`** (selector on **5V**) | VCC | Power — see note |
| GND | GND | Ground |

> **Supply: a BN-880 runs on 5 V, not 3.3 V.** It regulates down to 3.3 V on-module. Fed from the
> 3.3 V rail it sits at its regulator's dropout and browns out under acquisition current — which
> presents as flaky GPS or an intermittent compass, not as a power fault. Put the UART header's
> `5V` / `3V3` selector on **`5V`**. A bare QMC5883L breakout (no BN-880) is a 3.3 V part and does
> use the 3.3 V rail. Either way the SDA/SCL lines are 3.3 V logic.

> **The `SDA` and `SCL` pads are on the UNDERSIDE of the RX board** — two bare 1.6 mm pads, 2.2 mm
> apart, just north of the ESP32-C3 module, immediately above its 2.4 GHz antenna castellations and
> under the `(c) Ludwig Bre` silkscreen. They are labelled there. Nothing is exposed on the top side.
> Added in board revision **V2.2** (`Electronics/.../Rx/Changelog.txt`) — **a V2.1 board does not
> have them.** See the [BN-880 → RX wiring guide](../GPS_Wiring_BN880_RX.md) for a render.

> The I2C bus is shared — the AW9523 I/O expander (0x58) and the compass (QMC5883L at `0x0D` **or** QMC5883P at `0x2C`) both use the same SDA/SCL lines. Pull-up resistors are on the PCB; do not add external ones.

### Step 1 — Verify Compass Detection with `?i2c`

```
?i2c
```
Expected output — all I2C devices present. **Which compass line you get depends on the part you
fitted; either one is correct.**

With a **BN-880** (or an HGLRC M100 Pro) — QMC5883L at `0x0D`:

```
Scanning I2C bus (initialized on SDA:2 SCL:1)...
I2C device found at address 0x0D (QMC5883L Compass - BN-880) !
I2C device found at address 0x58 (AW9523 Expander) !
Scan complete.
```

With an **HGLRC M100-5883** — QMC5883P at `0x2C`:

```
Scanning I2C bus (initialized on SDA:2 SCL:1)...
I2C device found at address 0x2C (QMC5883P Compass - M100-5883) !
I2C device found at address 0x58 (AW9523 Expander) !
Scan complete.
```

If **neither** compass address appears:
- Check SDA (GPIO 2) and SCL (GPIO 1) wires match the table above
- Verify the supply is correct for your module — **5 V for a BN-880**, 3.3 V for a bare QMC5883L
  breakout — and that GND is connected
- If AW9523 is also missing, the entire I2C bus is open — check PCB solder joints

If you see `0x1E (HMC5883L Compass - NOT supported)`, you have very old BN-880 stock. That part is
reported but not driven — fit a BN-880 with a QMC5883L, or an M100-5883.

### Step 2 — Check Raw Compass Data with `?printcompass`
```
?printcompass
```

Rotate the RX board while watching X, Y, Z values. They must change as you rotate. Type `quit` to stop.

If values are all zero or completely static → compass power or wiring problem.

### Step 3 — Calibrate with `?compasscal`

Run before first use, after any mechanical change to the buggy installation, and **after re-mounting
or swapping the compass module**:

```
?compasscal
```

**Prerequisite — the module must be square to the buggy.** Its own forward axis lined up with the
nose, or turned exactly 90°, 180° or 270° from it. Not diagonal. The firmware stores the mounting
rotation only as one of those four values, so a module mounted at, say, 30° is stored as 0° and keeps
30° of heading error that no calibration can remove. Confirm this before running the procedure below.

**The procedure — the direction and the start/finish point both matter:**

1. **Point the nose of the buggy at NORTH.**
2. Run `?compasscal` (or short-press BIND on the RX). You have 45 seconds.
3. **Rotate SLOWLY CLOCKWISE — two full circles.** Keep the buggy level, away from anything metal.
4. **Finish with the nose back on NORTH.**

One run measures three things: the hard/soft-iron calibration, the mounting **handedness** (from
which way the heading ran while you turned clockwise), and the mounting **rotation** (from the first
sample, taken while you were pointing north). Clockwise is what reveals handedness; ending on north
is how the result is checked. Live min/max values print during rotation.

Tolerances are deliberately loose — **≥ 400° of total rotation and closure within ±40° of where you
started** — because a rejected run only costs you a re-walk. The stored rotation is snapped to
0 / 90 / 180 / 270.

**LED feedback on the BIND LED, and what it means:**

| Blinks | Meaning |
|---|---|
| **5 blinks** | **Started** — begin turning now |
| **2 blinks** | **Full success** — iron calibration, handedness and mounting orientation all updated |
| **3 blinks** | **PARTIAL** — iron calibration saved, **mounting orientation NOT updated** (the previous value was kept) |
| **10 blinks** | Nothing saved — no compass detected, or the buggy was barely turned |

**Three blinks is not a success.** Re-walk it — start on north, two full clockwise circles, finish on
north. This matters most **right after you re-mount or move the module**: the iron calibration then
matches the new mounting while the stored orientation still describes the old one, so every heading
is wrong by exactly that difference and Follow-Me veers by the same amount at close range. Serial
prints the same verdict in words, naming what was and was not updated.

**Diagnosing a residual error the calibration will not remove.** A completed run prints both the
angle it measured and the angle it stored:

```
Mounting orientation: measured 251 deg, stored 270 deg.
```

Those two should agree within a few degrees. **Anything larger is error that survives calibration**,
and it is the first thing to check when a compass still reads wrong after a clean 2-blink run. One
tester's four cardinal readings averaged a measured 251.25°, which snapped to a stored 270° — his
four post-calibration heading errors (−3.4°, −4.7°, −31.9°, −35.0°) then averaged −18.75°, exactly
the 251.25 − 270 gap, no matter how many times he re-ran the calibration. The fix is mechanical:
re-mount the module square and run `?compasscal` again. (The spread around that average is a
separate off-centre iron calibration, which re-running *does* fix.)

**Re-checking the mounting angle on its own — `?magalign`.** If the iron calibration is already good
and you only want to re-derive (or verify) the mounting orientation, point the nose at magnetic north,
hold it steady and run:

```
?magalign
```

It averages for 5 seconds, stores the orientation and saves — no circles. It **cannot** detect a
mirrored module; only `?compasscal` can, from the direction of the turn. It also refuses to run on a
compass that has never been calibrated, because it would then measure the hard-iron bias and call it a
mounting angle.

Calibration persists across reboots. Re-run any time the buggy's internal layout changes (motor,
battery, or electronics moved), and always after changing compass or GPS module — stored offsets are
raw counts and do not carry across a part change.

> Both `?compasscal` and `?magalign` are refused while Return-to-Me or Follow-Me is engaged, and
> abort themselves if either engages part-way through. An abandoned run changes nothing.

### Step 4 — Verify Live Heading with `?compassheading`
```
?compassheading
```

Prints heading in degrees every 500 ms. Type `quit` to stop.

- Point buggy nose North → reading near 0° (or 360°)
- Rotate 90° clockwise → ~90°
- Rotate 180° → ~180°

If heading is erratic → calibrate away from motors, batteries, and metal objects. Nearby magnets corrupt the reading.

---

## GPS Update Rate and Bench Testing Notes

The TX GPS update rate is controlled by `gps_update_hz` in TX SPIFFS (default: **2 Hz**).

- **2 Hz** — recommended for normal use. Conserves bandwidth on the LoRa link.
- **5 Hz** — recommended during RTM direction and steering tuning on a bench or in controlled water tests. Finer position updates help tune approach behavior and decel zone feel.

Set via TX web config or `?set gps_update_hz 5` in the TX serial monitor. Reboot TX to apply.

---

*Guide created: 2026-04-24 — based on real diagnosis during TX unit 1 build.*  

---

## Arduino IDE Board Settings

> 🚨 **The TX and RX need DIFFERENT partition settings, and using the TX's setting on the RX
> WIPES the RX's config, compass calibration and all on-board logs.** An earlier version of this
> appendix told you to use Huge App on both boards. That was wrong. The per-board flashing guides
> are the authority: **[RX →](../FLASHING_RX_ARDUINO.md)** · **[TX →](../FLASHING_TX_ARDUINO.md)**.

Both boards are an **ESP32-C3** (HT-CT62), so **Board = "ESP32C3 Dev Module"** on the TX *and* the RX.
There is no ESP32-S3 anywhere in BREmote.

### Partition Scheme — CRITICAL, and NOT the same on both boards

| Board | Tools → Partition Scheme | FQBN flag | Why |
|---|---|---|---|
| **TX** | **Huge APP (3 MB No OTA)** | `PartitionScheme=huge_app` | **Mandatory.** The TX has **no** `partitions.csv` of its own, so this flag is what decides the layout. NimBLE pushes the TX binary past the default 1.25 MB app slot — without it you get "Sketch too big". |
| **RX** | **"Custom"** | `PartitionScheme=custom` | The RX sketch ships its **own `partitions.csv`** (2.0 MB app + 1.875 MB SPIFFS). "Custom" means *"use the sketch's own table"* — the flashed layout is byte-identical to leaving it unset; only the size limit the tool checks against changes. |

> ⚠️ **NEVER select Huge APP on the RX.** A named scheme **replaces** the sketch's own table: SPIFFS
> collapses from 1.875 MB to about 0.9 MB **and moves**, so the filesystem reformats on the next mount.
> That means **your config, your pairing, your compass calibration and every on-board log are gone**,
> and you have half the logging space from then on. "Custom" and "Huge App" sound similar and do
> opposite things — read the row above twice.

> **Seeing "97% of program storage" on the RX? That is a FALSE reading, not a reason to switch.**
> With the scheme unset, arduino-cli measures the RX against a 1.25 MB limit that has nothing to do
> with the real 2.0 MB app slot. **Select "Custom", not "Huge App"** — Huge App IS the trap this note
> exists to keep you out of. Full explanation in [Flashing the RX](../FLASHING_RX_ARDUINO.md).

**What you lose on both boards:** OTA (over-the-air WiFi flashing) — not used in BREmote. Both boards
are flashed over USB, so nothing is lost.

**If you do change the RX's partition scheme by accident:** back up first next time (`?conf` prints a
Base64 blob; `?setconf <blob>` then `?applyconf` restores it), and expect to re-pair and re-run
`?compasscal` — physically, two full clockwise circles — to recover.

### Other settings (both boards)

| Setting | Value | Why |
|---|---|---|
| **USB CDC On Boot** | **Disabled** (`CDCOnBoot=default`) | GPIO 18/19 are the USB D-/D+ pins **and** the GPS UART (Serial1). Enabling CDC makes USB claim those pins → **the GPS silently dies.** |
| Flash Size | 4 MB | |
| Flash Mode / Freq | QIO / 80 MHz (defaults) | |
| Upload Speed | 921600 | |
| Serial Monitor | 115200 | |

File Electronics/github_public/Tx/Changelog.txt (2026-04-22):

Changelog Display Board

V2.3:
- Initial version after decision to have HT-CT62 on top board
V2.4:
- Swapped Rx and Tx Lines on CH340 (bottom board)
- Moved vias underneath HT-CT62 so they align with pads
- Added a GND via to bottom board
- Moved Pin1-whiteprint of 2.4GHz antenna to correct place
- Add version identifier
- Change antenna network

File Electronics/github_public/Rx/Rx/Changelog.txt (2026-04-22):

Changelog Rx

V2.1:
- Initial version
V2.2:
- Change supply for CH340K to before USB diode
- Add SDA and SCL pads

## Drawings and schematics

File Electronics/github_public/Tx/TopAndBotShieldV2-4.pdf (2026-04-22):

05.05.2025 14:25 f=0.80 C:\Users\rcb8fe\Desktop\prep_order\Tx\final\github_public\TopAndBotShieldV2-4.sch (Sheet: 1/1) ¹⁰uF shared with TP⁴⁰⁵⁶ | 24⁻pin: Place 0R
R7 6 | C¹

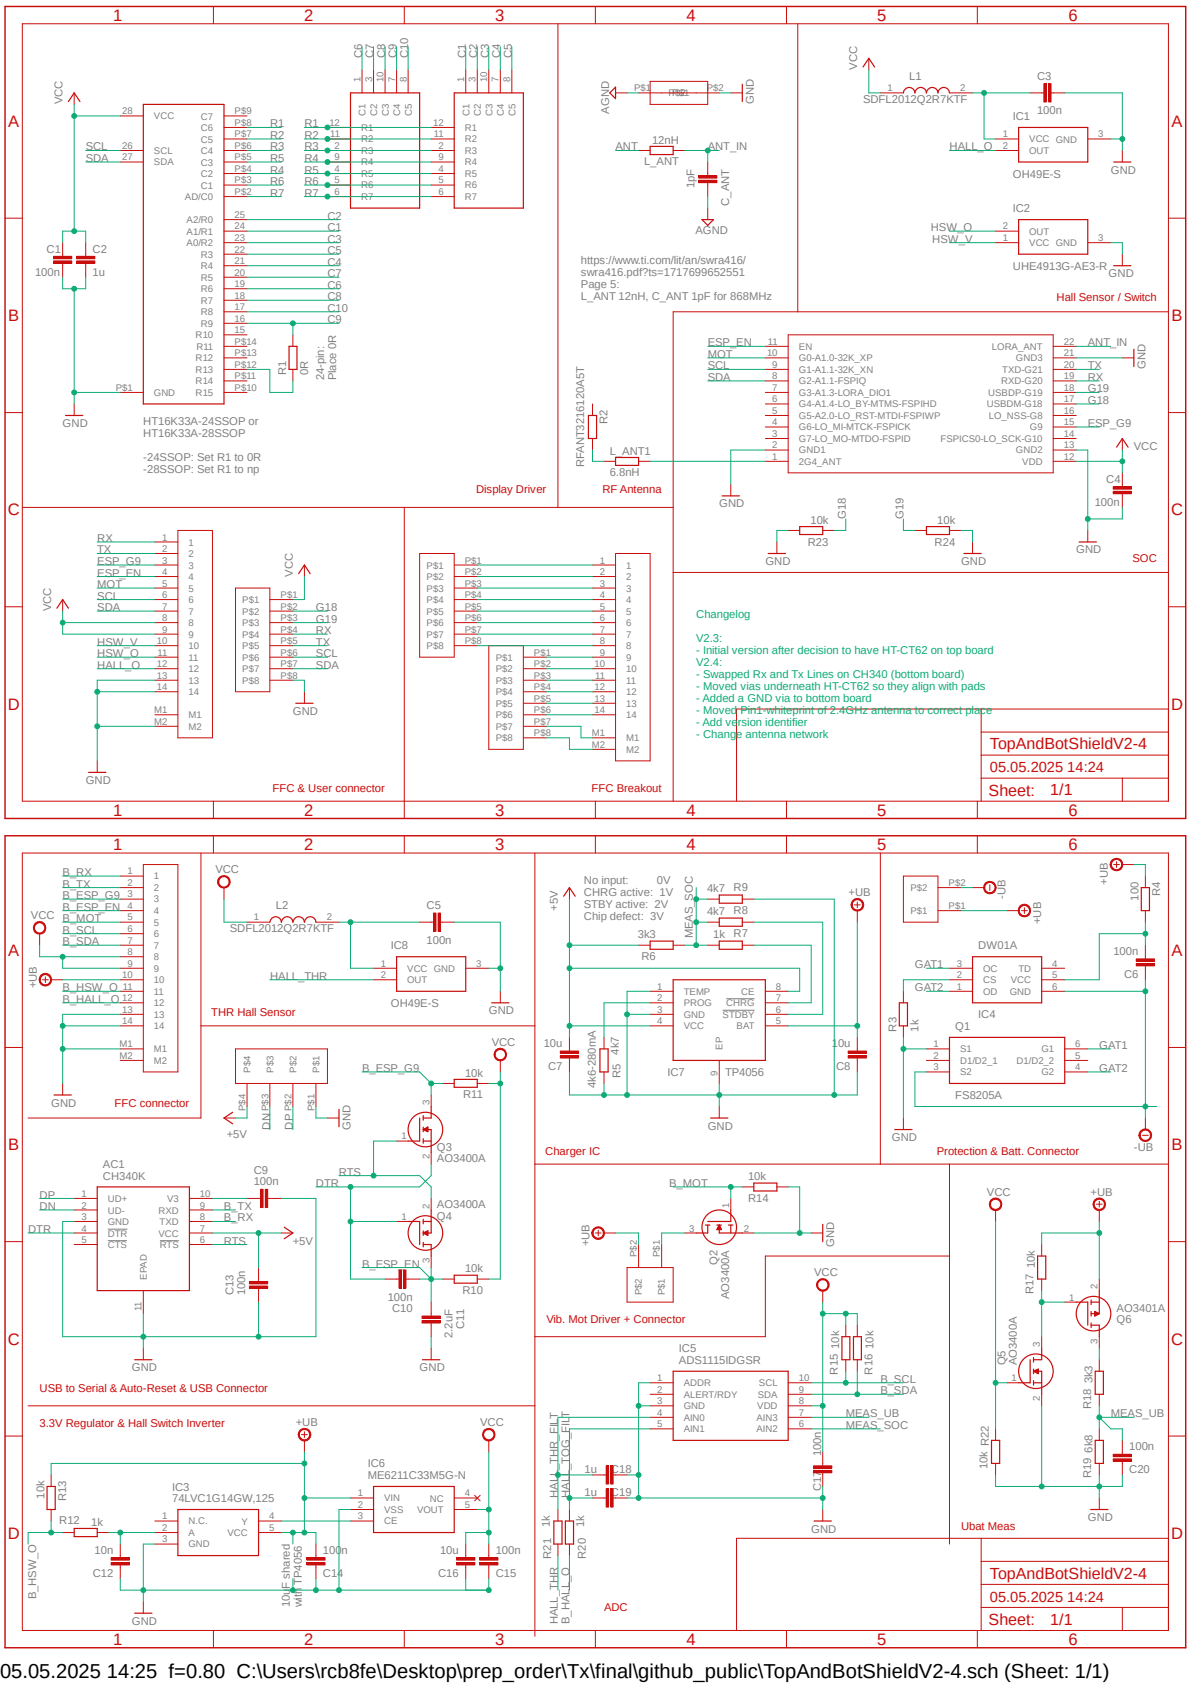
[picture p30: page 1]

SDFL2012Q2R7KTF VCC GND AGND VCC

https://www.ti.com/lit/an/swra416/
swra416.pdf?ts=1717699652551
Page 5:
L_ANT 12nH, C_ANT 1pF for 868MHz

Changelog
- Initial version after decision to have HT-CT62 on top board
- Swapped Rx and Tx Lines on CH340 (bottom board)
- Moved vias underneath HT-CT62 so they align with pads
- Added a GND via to bottom board
- Moved Pin1-whiteprint of 2.4GHz antenna to correct place
- Add version identifier
- Change antenna network

VCC | No input: 0V

Vib. Mot Driver + Connector

USB to Serial & Auto-Reset & USB Connector

VCC 10k
3.3V Regulator & Hall Switch Inverter

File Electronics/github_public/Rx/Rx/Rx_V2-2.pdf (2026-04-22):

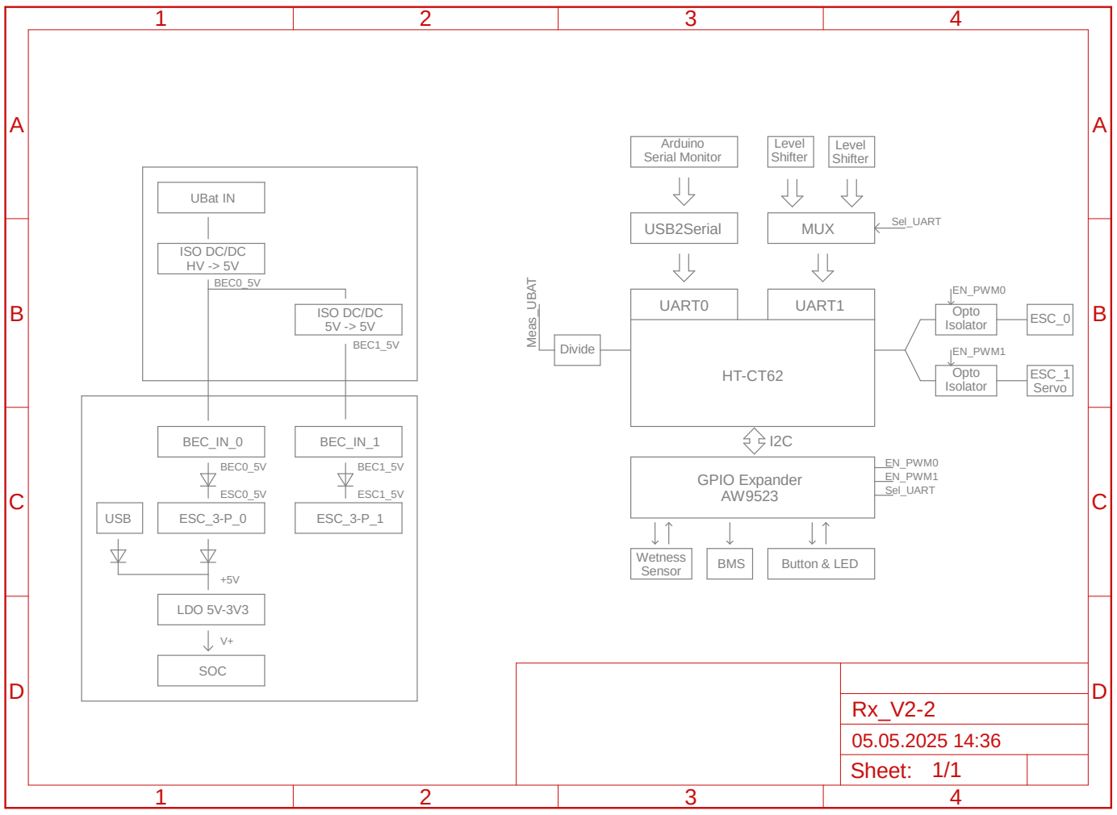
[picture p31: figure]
UART0; UART1; USB2Serial; MUX; Level Shifter; Arduino Serial Monitor; Opto Isolator; ESC_0; ESC_1 Servo; EN_PWM0; EN_PWM1; Sel_UART; Divide Meas_UBAT; GPIO Expander AW9523; I2C Wetness Sensor; BMS; Button & LED; EN_PWM0 EN_PWM1 Sel_UART; BEC_IN_0; ESC_3-P_0; LDO 5V-3V3; BEC_IN_1; ESC_3-P_1; SOC; ISO DC/DC HV -> 5V; ISO DC/DC; 5V -> 5V UBat IN; USB; ESC0_5V; BEC0_5V; BEC1_5V; ESC1_5V; Sheet:

05.05.2025 14:57 f=1.05 C:\Users\rcb8fe\Desktop\prep_order\Tx\final\openfoil\Rx\Rx_V2-2.sch (Sheet: 1/1)

# 1k GND

# IC3 A

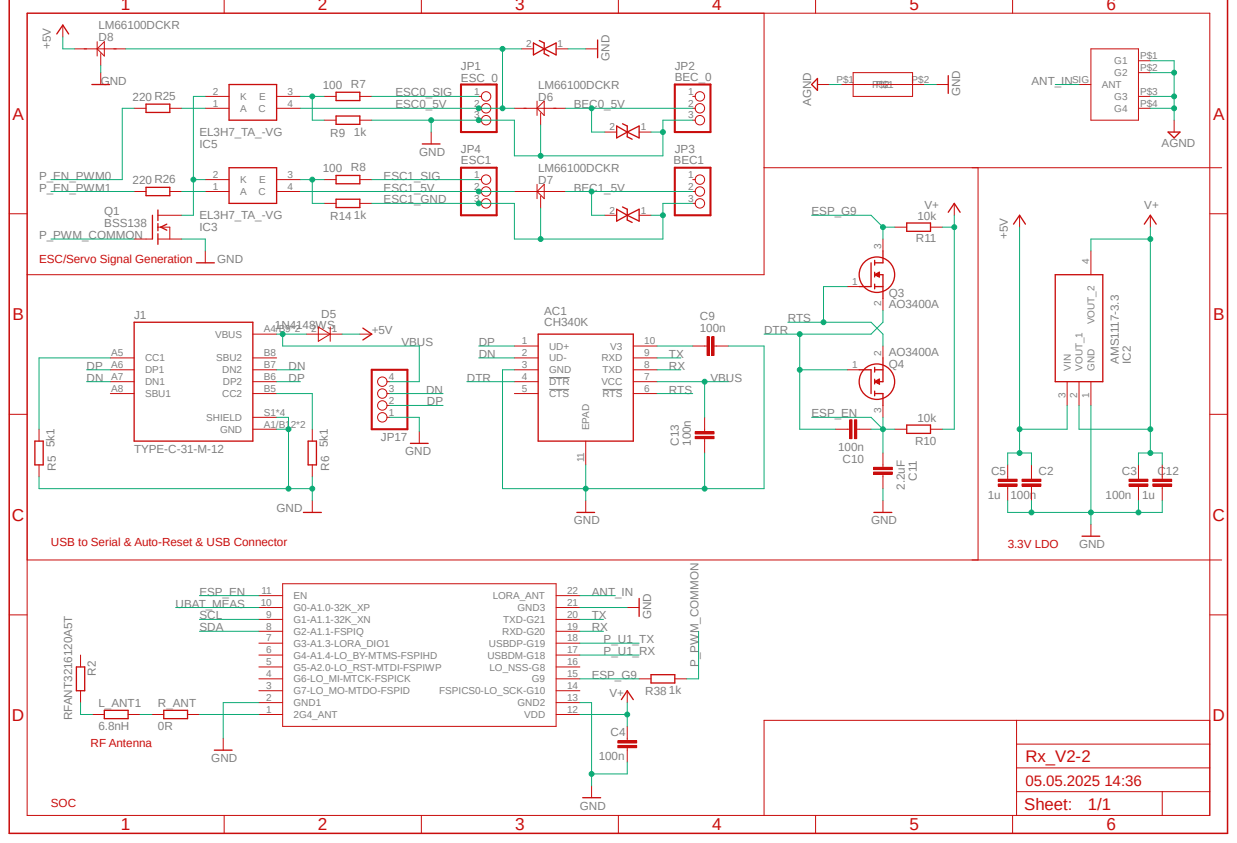
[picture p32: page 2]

ESC/Servo Signal Generation

V+ | BSS¹³⁸ 10k | 10k

A

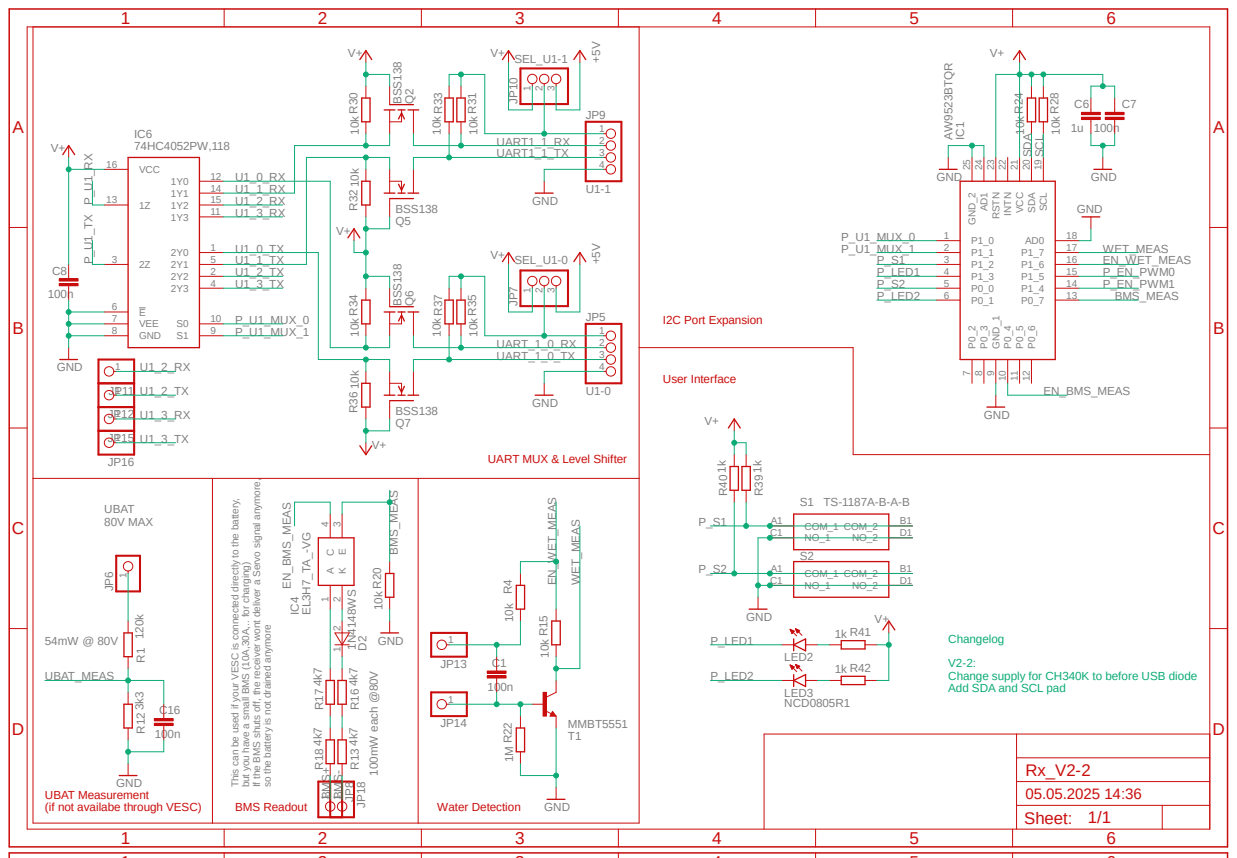
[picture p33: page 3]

UART MUX & Level Shifter

Changelog
Change supply for CH340K to before USB diode
Add SDA and SCL pad

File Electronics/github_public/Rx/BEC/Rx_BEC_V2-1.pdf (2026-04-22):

A

B

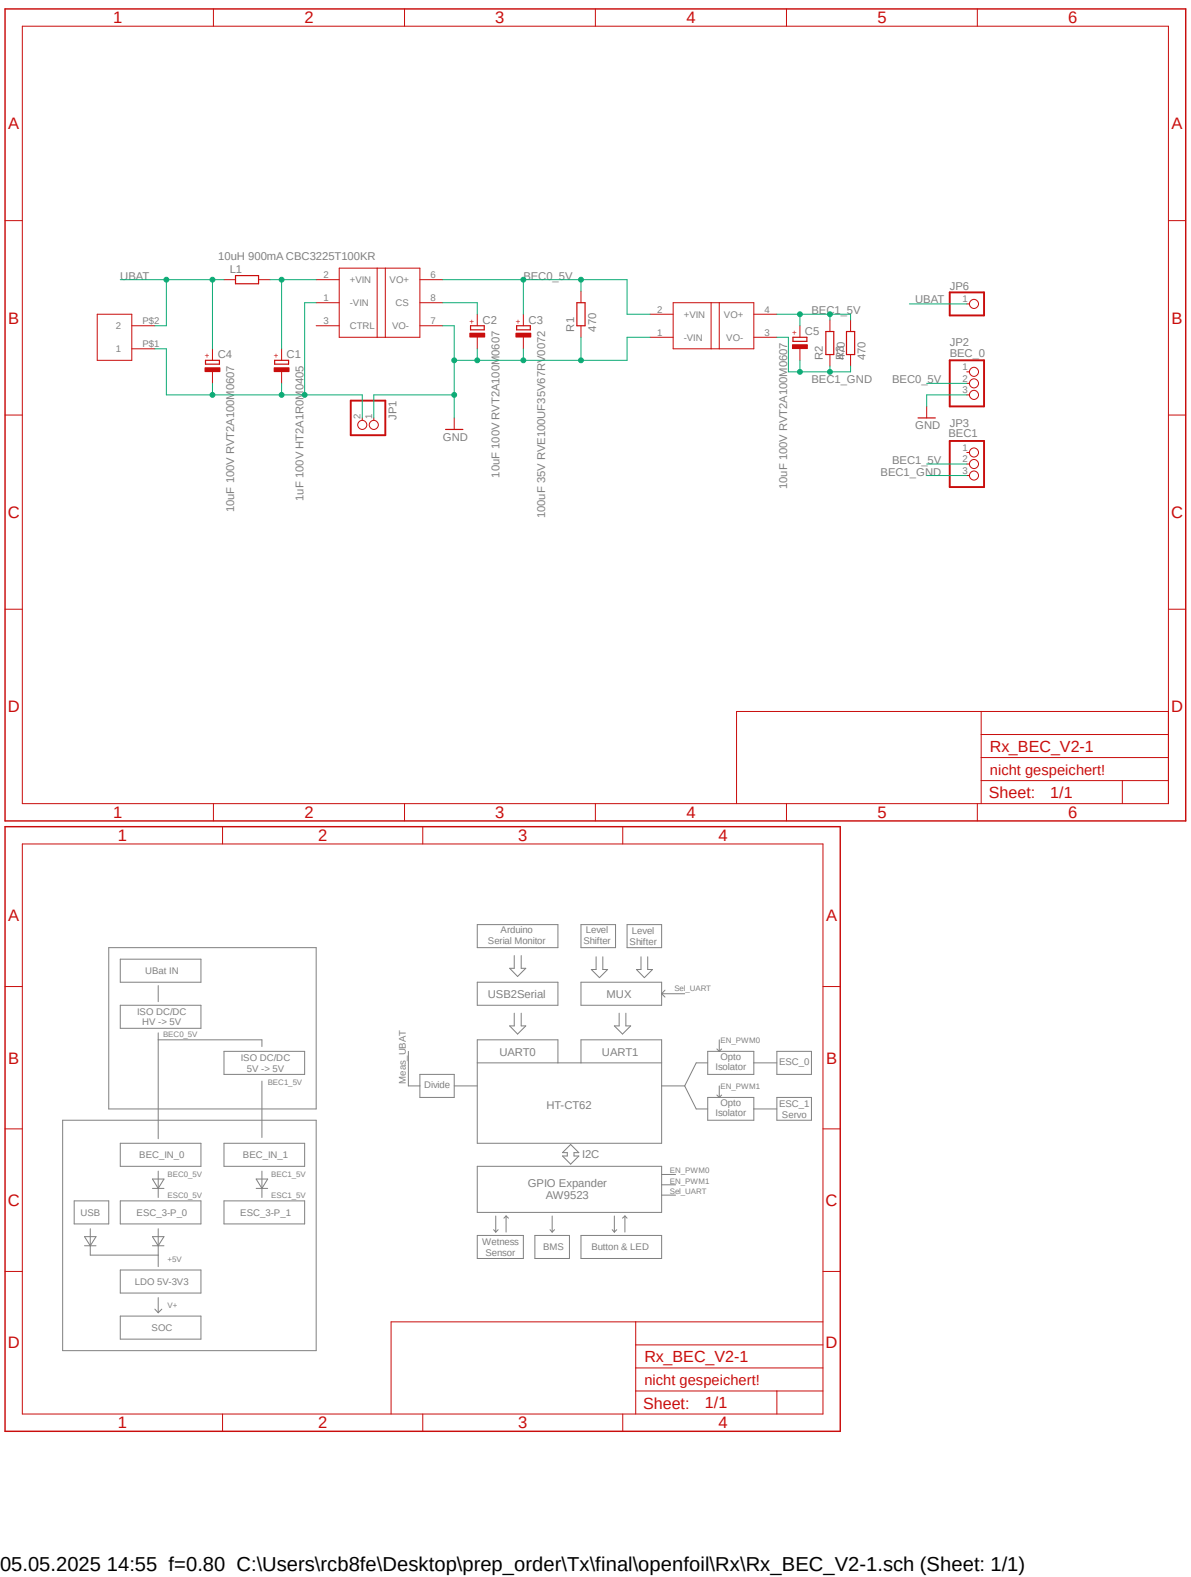
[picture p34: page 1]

+VIN 2 | CS

-VIN 1 | 8

05.05.2025 14:55 f=0.80 C:\Users\rcb8fe\Desktop\prep_order\Tx\final\openfoil\Rx\Rx_BEC_V2-1.sch (Sheet: 1/1)

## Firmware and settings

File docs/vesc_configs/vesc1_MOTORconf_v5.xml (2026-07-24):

<?xml version="1.0" encoding="UTF-8"?>
<MCConfiguration>
    <pwm_mode>1</pwm_mode>
    <comm_mode>0</comm_mode>
    <motor_type>2</motor_type>
    <sensor_mode>0</sensor_mode>
    <l_current_max>95</l_current_max>
    <l_current_min>-60</l_current_min>
    <l_in_current_max>100</l_in_current_max>
    <l_in_current_min>-20</l_in_current_min>
    <l_in_current_map_start>1</l_in_current_map_start>
    <l_in_current_map_filter>0.005</l_in_current_map_filter>
    <l_abs_current_max>250</l_abs_current_max>
    <l_min_erpm>-100000</l_min_erpm>
    <l_max_erpm>100000</l_max_erpm>
    <l_erpm_start>0.8</l_erpm_start>
    <l_max_erpm_fbrake>300</l_max_erpm_fbrake>
    <l_max_erpm_fbrake_cc>1500</l_max_erpm_fbrake_cc>
    <l_min_vin>23</l_min_vin>
    <l_max_vin>72</l_max_vin>
    <l_battery_cut_start>32</l_battery_cut_start>
    <l_battery_cut_end>29</l_battery_cut_end>
    <l_battery_regen_cut_start>1000</l_battery_regen_cut_start>
    <l_battery_regen_cut_end>1100</l_battery_regen_cut_end>
    <l_slow_abs_current>0</l_slow_abs_current>
    <l_temp_fet_start>85</l_temp_fet_start>
    <l_temp_fet_end>100</l_temp_fet_end>
    <l_temp_motor_start>85</l_temp_motor_start>
    <l_temp_motor_end>100</l_temp_motor_end>
    <l_temp_accel_dec>0.15</l_temp_accel_dec>
    <l_min_duty>0.005</l_min_duty>
    <l_max_duty>0.96</l_max_duty>
    <l_watt_max>1.5e+06</l_watt_max>
    <l_watt_min>-1.5e+06</l_watt_min>
    <l_current_max_scale>1</l_current_max_scale>
    <l_current_min_scale>1</l_current_min_scale>
    <l_duty_start>1</l_duty_start>
    <sl_min_erpm>150</sl_min_erpm>
    <sl_min_erpm_cycle_int_limit>1100</sl_min_erpm_cycle_int_limit>
    <sl_max_fullbreak_current_dir_change>10</sl_max_fullbreak_current_dir_change>
    <sl_cycle_int_limit>62</sl_cycle_int_limit>
    <sl_phase_advance_at_br>0.8</sl_phase_advance_at_br>
    <sl_cycle_int_rpm_br>80000</sl_cycle_int_rpm_br>
    <sl_bemf_coupling_k>600</sl_bemf_coupling_k>
    <hall_table__0>-1</hall_table__0>
    <hall_table__1>1</hall_table__1>
    <hall_table__2>3</hall_table__2>
    <hall_table__3>2</hall_table__3>
    <hall_table__4>5</hall_table__4>
    <hall_table__5>6</hall_table__5>
    <hall_table__6>4</hall_table__6>
    <hall_table__7>-1</hall_table__7>
    <hall_sl_erpm>2000</hall_sl_erpm>
    <foc_current_kp>0.0182</foc_current_kp>
    <foc_current_ki>23.82</foc_current_ki>
    <foc_f_zv>30000</foc_f_zv>
    <foc_dt_us>0.12</foc_dt_us>
    <foc_encoder_inverted>0</foc_encoder_inverted>
    <foc_encoder_offset>180</foc_encoder_offset>
    <foc_encoder_ratio>7</foc_encoder_ratio>
    <foc_sensor_mode>0</foc_sensor_mode>
    <foc_pll_kp>2000</foc_pll_kp>
    <foc_pll_ki>30000</foc_pll_ki>
    <foc_motor_l>1.82e-05</foc_motor_l>
    <foc_motor_ld_lq_diff>1.184e-05</foc_motor_ld_lq_diff>
    <foc_motor_r>0.0238</foc_motor_r>
    <foc_motor_flux_linkage>0.004922</foc_motor_flux_linkage>
    <foc_observer_gain>4.128e+07</foc_observer_gain>
    <foc_observer_gain_slow>0.05</foc_observer_gain_slow>
    <foc_observer_offset>-1</foc_observer_offset>
    <foc_duty_dowmramp_kp>50</foc_duty_dowmramp_kp>
    <foc_duty_dowmramp_ki>1000</foc_duty_dowmramp_ki>
    <foc_start_curr_dec>1</foc_start_curr_dec>
    <foc_start_curr_dec_rpm>1520</foc_start_curr_dec_rpm>
    <foc_openloop_rpm>1000</foc_openloop_rpm>
    <foc_openloop_rpm_low>0</foc_openloop_rpm_low>
    <foc_d_gain_scale_start>0.9</foc_d_gain_scale_start>
    <foc_d_gain_scale_max_mod>0.9</foc_d_gain_scale_max_mod>
    <foc_sl_openloop_hyst>0.1</foc_sl_openloop_hyst>
    <foc_sl_openloop_time_lock>0.05</foc_sl_openloop_time_lock>
    <foc_sl_openloop_time_ramp>0.2</foc_sl_openloop_time_ramp>
    <foc_sl_openloop_time>0.05</foc_sl_openloop_time>
    <foc_sl_openloop_boost_q>3</foc_sl_openloop_boost_q>
    <foc_sl_openloop_max_q>-1</foc_sl_openloop_max_q>
    <foc_hall_table__0>255</foc_hall_table__0>
    <foc_hall_table__1>255</foc_hall_table__1>
    <foc_hall_table__2>255</foc_hall_table__2>
    <foc_hall_table__3>255</foc_hall_table__3>
    <foc_hall_table__4>255</foc_hall_table__4>
    <foc_hall_table__5>255</foc_hall_table__5>
    <foc_hall_table__6>255</foc_hall_table__6>
    <foc_hall_table__7>255</foc_hall_table__7>
    <foc_hall_interp_erpm>500</foc_hall_interp_erpm>
    <foc_sl_erpm_start>2250</foc_sl_erpm_start>
    <foc_sl_erpm>2510</foc_sl_erpm>
    <foc_control_sample_mode>0</foc_control_sample_mode>
    <foc_current_sample_mode>0</foc_current_sample_mode>
    <foc_sat_comp_mode>0</foc_sat_comp_mode>
    <foc_sat_comp>0</foc_sat_comp>
    <foc_temp_comp>0</foc_temp_comp>
    <foc_temp_comp_base_temp>25</foc_temp_comp_base_temp>
    <foc_current_filter_const>0.1</foc_current_filter_const>
    <foc_cc_decoupling>0</foc_cc_decoupling>
    <foc_observer_type>3</foc_observer_type>
    <foc_hfi_amb_mode>0</foc_hfi_amb_mode>
    <foc_hfi_amb_current>60</foc_hfi_amb_current>
    <foc_hfi_amb_tres>15</foc_hfi_amb_tres>
    <foc_hfi_voltage_start>20</foc_hfi_voltage_start>
    <foc_hfi_voltage_run>4</foc_hfi_voltage_run>
    <foc_hfi_voltage_max>6</foc_hfi_voltage_max>
    <foc_hfi_gain>0.3</foc_hfi_gain>
    <foc_hfi_max_err>0.3</foc_hfi_max_err>
    <foc_hfi_hyst>0</foc_hfi_hyst>
    <foc_sl_erpm_hfi>3000</foc_sl_erpm_hfi>
    <foc_hfi_start_samples>5</foc_hfi_start_samples>
    <foc_hfi_obs_ovr_sec>0.001</foc_hfi_obs_ovr_sec>
    <foc_hfi_samples>1</foc_hfi_samples>
    <foc_offsets_cal_mode>1</foc_offsets_cal_mode>
    <foc_offsets_current__0>2008.31</foc_offsets_current__0>
    <foc_offsets_current__1>2031.99</foc_offsets_current__1>
    <foc_offsets_current__2>2059.8</foc_offsets_current__2>
    <foc_offsets_voltage__0>-0.0008</foc_offsets_voltage__0>
    <foc_offsets_voltage__1>-0.0025</foc_offsets_voltage__1>
    <foc_offsets_voltage__2>0.0033</foc_offsets_voltage__2>
    <foc_offsets_voltage_undriven__0>0</foc_offsets_voltage_undriven__0>
    <foc_offsets_voltage_undriven__1>0</foc_offsets_voltage_undriven__1>
    <foc_offsets_voltage_undriven__2>0</foc_offsets_voltage_undriven__2>
    <foc_phase_filter_enable>0</foc_phase_filter_enable>
    <foc_phase_filter_disable_fault>0</foc_phase_filter_disable_fault>
    <foc_phase_filter_max_erpm>4000</foc_phase_filter_max_erpm>
    <foc_mtpa_mode>0</foc_mtpa_mode>
    <foc_fw_current_max>0</foc_fw_current_max>
    <foc_fw_duty_start>0.9</foc_fw_duty_start>
    <foc_fw_q_current_factor>0.02</foc_fw_q_current_factor>
    <foc_fw_ramp_time>0.2</foc_fw_ramp_time>
    <foc_speed_soure>0</foc_speed_soure>
    <foc_short_ls_on_zero_duty>0</foc_short_ls_on_zero_duty>
    <foc_overmod_factor>1</foc_overmod_factor>
    <sp_pid_loop_rate>5</sp_pid_loop_rate>
    <s_pid_kp>0.004</s_pid_kp>
    <s_pid_ki>0.004</s_pid_ki>
    <s_pid_kd>0.0001</s_pid_kd>
    <s_pid_kd_filter>0.2</s_pid_kd_filter>
    <s_pid_min_erpm>900</s_pid_min_erpm>
    <s_pid_allow_braking>1</s_pid_allow_braking>
    <s_pid_ramp_erpms_s>-1</s_pid_ramp_erpms_s>
    <s_pid_speed_source>0</s_pid_speed_source>
    <p_pid_kp>0.025</p_pid_kp>
    <p_pid_ki>0</p_pid_ki>
    <p_pid_kd>0</p_pid_kd>
    <p_pid_offset>0</p_pid_offset>
    <p_pid_kd_proc>0.00035</p_pid_kd_proc>
    <p_pid_kd_filter>0.2</p_pid_kd_filter>
    <p_pid_ang_div>1</p_pid_ang_div>
    <p_pid_gain_dec_angle>0</p_pid_gain_dec_angle>
    <cc_startup_boost_duty>0.01</cc_startup_boost_duty>
    <cc_min_current>0.05</cc_min_current>
    <cc_gain>0.0046</cc_gain>
    <cc_ramp_step_max>0.04</cc_ramp_step_max>
    <m_fault_stop_time_ms>500</m_fault_stop_time_ms>
    <m_duty_ramp_step>0.02</m_duty_ramp_step>
    <m_current_backoff_gain>0.5</m_current_backoff_gain>
    <m_encoder_counts>8192</m_encoder_counts>
    <m_encoder_sin_amp>1</m_encoder_sin_amp>
    <m_encoder_cos_amp>1</m_encoder_cos_amp>
    <m_encoder_sin_offset>1.65</m_encoder_sin_offset>
    <m_encoder_cos_offset>1.65</m_encoder_cos_offset>
    <m_encoder_sincos_filter_constant>0.5</m_encoder_sincos_filter_constant>
    <m_encoder_sincos_phase_correction>0</m_encoder_sincos_phase_correction>
    <m_sensor_port_mode>0</m_sensor_port_mode>
    <m_invert_direction>1</m_invert_direction>
    <m_drv8301_oc_mode>0</m_drv8301_oc_mode>
    <m_drv8301_oc_adj>16</m_drv8301_oc_adj>
    <m_bldc_f_sw_min>3000</m_bldc_f_sw_min>
    <m_bldc_f_sw_max>35000</m_bldc_f_sw_max>
    <m_dc_f_sw>25000</m_dc_f_sw>
    <m_ntc_motor_beta>3380</m_ntc_motor_beta>
    <m_out_aux_mode>0</m_out_aux_mode>
    <m_motor_temp_sens_type>0</m_motor_temp_sens_type>
    <m_ptc_motor_coeff>0.61</m_ptc_motor_coeff>
    <m_ntcx_ptcx_res>10000</m_ntcx_ptcx_res>
    <m_ntcx_ptcx_temp_base>25</m_ntcx_ptcx_temp_base>
    <m_hall_extra_samples>3</m_hall_extra_samples>
    <m_batt_filter_const>50</m_batt_filter_const>
    <si_motor_poles>14</si_motor_poles>
    <si_gear_ratio>1</si_gear_ratio>
    <si_wheel_diameter>0.155</si_wheel_diameter>
    <si_battery_type>0</si_battery_type>
    <si_battery_cells>10</si_battery_cells>
    <si_battery_ah>30</si_battery_ah>
    <si_motor_nl_current>0.6</si_motor_nl_current>
    <motor_brand></motor_brand>
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

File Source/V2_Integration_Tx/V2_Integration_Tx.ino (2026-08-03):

// V2.5-Evo - 2026-07-20 - BLE re-enable deep-fix (Rex): the per-loop bleTelemetryLoop()/extTelemNotify() pushes are REMOVED from loop(); the periodic BLE telemetry push now lives in the dedicated Core-0 bleNotifyTask (see Init.ino/BLE.ino) so BLE cadence can't couple to display-render timing.
// V2.5-Evo - 2026-07-20 - MagGesture FIX1: with mag_mode>0 the Hall is EXCLUSIVELY the FM/RTM gesture input — the SW33b tap→bt_dot_state (BLE-session) toggle is gated OFF and the BT dot is instead driven from BLE state (bt_enabled==2/boot-gesture). mag_mode==0 SW33b behaviour is byte-identical to baseline.
// V2.5-Evo - 2026-07-20 - MagGesture: runMagGesture() called from loop() after the SW33b Hall block; prototype added
// *** LATEST: V2.5-Evo - 2026-05-15 - feature/bluetooth Tier 1: NUS skeleton (BLE.ino); bt_enabled SPIFFS field; boot gesture; bleInitTask 5s delayed ***
// V2.5-Evo - 2026-05-14 - SW55 — bootAnimation VI 250ms / voltage 1450ms; padlock at ~4.5s total boot
// V2.5-Evo - 2026-05-13 - SW33: Removed GPIO 9 from serialOff OUTPUT-LOW block (P_MAG reserved for DRV5032 Hall sensor)
// V2.5-Evo - 2026-05-13 - SW33b: Hall mag reading state machine added to loop(); drives bt_dot_state
// V2.5-Evo - 2026-05-03 - Removed commented-out SPIFFS.remove dead code (LOW audit cleanup)
// V2.5-Evo - 2026-04-25 - P7: Simplified getTxGPSLoop() gate to gps_en only; added runRtmLoop() call in loop()
// V2.5-Evo - 2026-04-24 - Call initTxGPS() in setup() after applyConfigSettings() so GPS UART is ready on boot
// V2.5-Evo - 2026-04-21 - Added getTxGPSLoop() call in loop() and forward declarations for TX GPS functions
// V2.5-Evo - 2026-04-27 - P8: loop() calls renderRtmInfoDisplay() instead of renderOperationalDisplay() when rtm_tx_active
// V2.5-Evo - 2026-04-29 - Sleep: dual-condition auto-sleep — user idle (no throttle/toggle
//   above deadzone) OR RX silent; both use sleep_timeout_s; pocket-safe thresholds applied
#include "BREmote_V2_Tx.h"
// Function prototypes — forward declarations to resolve Arduino IDE ordering issues
// Init & Setup Functions
void initHardware();
void initStorage();
void checkCharger();
void initTasks();
void runBootSequence();
void applyConfigSettings();
void initWatchdog();
// Loop & System Functions
void serPrintPackets(bool json);
void runMenu();
void runMagGesture();   // magnet/Hall arm gesture (defined in Hall.ino) — loop()-only, may block
void renderOperationalDisplay();
void showFullScreenMessage(const char* msg, uint16_t duration_ms);
void deepSleep();
void checkSerial();
// Subsystem Activity Toggles
void setRadioActivityEnabled(bool enabled);
bool isRadioActivityEnabled();
void setHallActivityEnabled(bool enabled);
bool isHallActivityEnabled();
void setDisplayActivityEnabled(bool enabled);
bool isDisplayActivityEnabled();
// Throttle Functions
uint8_t calcFinalThrottle();
void throttleInit();
void throttleReset();
void throttleAdjustCap(int direction);
bool throttleUsesGears();
bool throttleForceToggleBlock();
uint8_t throttleGetCapPercent();
// TX GPS Functions (defined in GPS.ino, declared here as GPS.ino is concatenated after this file)
void initTxGPS();
void getTxGPSLoop();
// V2.5-Evo - 2026-07-20 - canonical "trustworthy fix" gate; shared by getTxGPSLoop() publish path and the Display.ino GPS status dot.
bool txGpsGoodFix();
// RTM & FM State Machine Functions (defined in RTMState.ino)
void runRtmLoop();
void runFmLoop();
void setRtmArmed();
void cycleFmMode();
void cycleFmModeArmed();
bool isFmArmed();
// V2.5-Evo - 2026-07-20 - Batch T: FM readiness helpers (defined in RTMState.ino, called from Display.ino).
bool fmArmedNotReady();     // true when FM is armed but not READY → scanner blinks in place instead of sweeping
bool fmFundamentalReject(); // true when a fresh FM arm must be refused (unpaired / no packet ever / no GPS fix ever)
uint8_t calcRtmThrottleCap();
// RTM/FM Active Display (defined in Display.ino)
void renderRtmInfoDisplay();
// BLE Functions (defined in BLE.ino)
// V2.5-Evo - 2026-06-04 - Guarded by BLE_ENABLED (BREmote_V2_Tx.h). When undefined, the
// NimBLE header is excluded, so these decls (one uses NimBLEServer*) must be excluded too.
// Optional extended-telemetry module. Present in some builds, absent in others; the build
// adapts either way with no flag to set. Core BLE (NUS / VESC) is unaffected in both cases.
#if defined(__has_include)
  #if __has_include("BLE_Ext.h")
    #include "BLE_Ext.h"
  #endif
#endif

#ifdef BLE_ENABLED
void initBLE();
// V2.5-Evo - 2026-07-20 - true on a live BLE connection; Display.ino uses it to make the BT dot SOLID (defined in BLE.ino).
bool bleIsConnected();
// V2.5-Evo - 2026-07-20 - BLE re-enable deep-fix (Rex §4.4/§4.5): consolidated back-pressured push
// (bleServiceNotify), the dedicated Core-0 push task (bleNotifyTask), and the optional-module stream helpers.
void bleServiceNotify();
void bleNotifyTask(void* param);
#ifdef EXT_TELEM_ENABLED
void initExtTelem(NimBLEServer* srv);
bool sendExtTelem();
bool extTelemHasSubscriber();
void extTelemClearSubscriber();
#endif
#endif
// Aux control command (defined in Radio.ino — queues 0xF4 meta-packet burst to RX)
void sendAuxCommand(uint8_t flags);
// Cross-Tab Subsystem Initializers
void startupRadio();
void startupDisplay();
void initSPIFFS();
void getConfFromSPIFFS();
void getBCFromSPIFFS();
void ICACHE_RAM_ATTR packetReceived(void);
// FreeRTOS Task Functions
void sendData(void *parameter);
void waitForTelemetry(void *parameter);
void updateBargraphs(void *parameter);
void measBufCalc(void *parameter);
void vibrationTask(void *parameter);   // haptic feedback task — drives vibration motor patterns
// -----------------------------------------------------------------------

SX1262 radio = new Module(P_LORA_NSS, P_LORA_DIO, P_LORA_RST, P_LORA_BUSY);
Adafruit_ADS1115 ads;
//Ticker ticksrc; // Unused — replaced by FreeRTOS tasks
// V2.5-Evo - 2026-04-29 - Sleep: SLEEP_TIMEOUT_MS removed; timeout now read from
// usrConf.sleep_timeout_s (SPIFFS). 0 = disabled. Default 300s = 5 minutes.

// Tracks time of last intentional user input for inactivity sleep.
// Reset when throttle is pulled above noise floor or toggle moves off center.
// Pocket-safe: ADC noise and accidental contact below these thresholds are ignored.
static unsigned long last_user_input_ms  = 0;
static uint8_t       last_sleep_steer    = 127;  // last known steer_scaled; 127=centre

void setup()
{
  in_setup = true;
  enterSetup();

  initHardware();
  initStorage();
  
  checkCharger();
  initTasks();
  runBootSequence();
  applyConfigSettings();
  // V2.5-Evo - 2026-04-24 - Call initTxGPS() on boot so GPS UART is ready before loop() starts polling
  initTxGPS();
  initWatchdog();

  exitSetup();
  in_setup = false;

// ... (rest of the setup function remains the same)

  if(system_locked)
  {
    setRadioActivityEnabled(false);
  }
  else
  {
#ifdef WIFI_ENABLED
    webCfgNotifyTxUnlocked();
#endif
  }

  if(config_version_error)
  {
    serialOff = false;
  }

  delay(100);
  if(serialOff)
  {
    Serial.end();
    digitalWrite(20, LOW); pinMode(20, OUTPUT);
    digitalWrite(21, LOW); pinMode(21, OUTPUT);
  }
}

void loop()
{
  if(config_version_error)
  {
    scroll3Digits(LET_E, 5, LET_V, 200);
    checkSerial();
    return;
  }

#ifdef WIFI_ENABLED
  webCfgLoop();
#endif

  // V2.5-Evo - 2026-04-25 - P7: Run GPS loop whenever gps_en=1, regardless of speed_src.
  // RTM mode needs TX GPS position for meta-packets even when speed display uses
  // an RX-side source (speed_src 0/1/4). Non-blocking — safe every 110ms tick.
  if (usrConf.gps_en)
  {
    getTxGPSLoop();
  }

  runMenu();
  if(in_menu > 0) in_menu--;

  // V2.5-Evo - 2026-04-25 - P7: RTM state machine (arming, active, cooldown) and FM mode cycle.
  runRtmLoop();
  // V2.5-Evo - 2026-04-27 - P8.1: FM arm/disarm state machine (arm window + Gate 1 throttle-release)
  runFmLoop();

  // V2.5-Evo - 2026-05-13 - SW33b: Hall mag sensor (P_MAG / GPIO 9) — polled every 20ms.
  // Drives bt_dot_state: short hold (400ms-4999ms) toggles OFF/SLOW; long hold (5s+) → FAST; FAST + any release → OFF.
  //
  // V2.5-Evo - 2026-07-20 - MagGesture FIX1: THE BUG — with mag_mode>0 and the DRV5032 fitted, a short
  // magnet tap fell through this legacy SW33b path and toggled bt_dot_state, which for bt_enabled==1
  // toggles the BLE session on/off (see BLE.ino bleTelemetryLoop active-gate) and always flips the BT
  // status dot. That collided with the FM/RTM magnet gesture: a sub-2s tap that armed nothing still
  // flipped BLE/the dot. THE FIX — when mag_mode>0 the Hall is EXCLUSIVELY the FM/RTM gesture input:
  // the tap→bt_dot_state toggle below is gated to mag_mode==0 only, and with mag_mode>0 the dot is
  // driven from the actual BLE state instead (bt_enabled==2 "always on" / boot-gesture bt_session_forced),
  // so a magnet tap can never change BLE or the dot. mag_seen_high is still updated unconditionally
  // (runMagGesture() depends on it). When mag_mode==0 this block is byte-identical to baseline.
  {
    static bool     mag_was_low   = false;
    static uint32_t mag_low_since = 0;
    static uint32_t mag_check_ms  = 0;
    if (millis() - mag_check_ms >= 20)
    {
      mag_check_ms = millis();
      if (digitalRead(P_MAG) == HIGH) mag_seen_high = true;
      bool mag_low = mag_seen_high && (digitalRead(P_MAG) == LOW);
      if (mag_low && !mag_was_low)
      {
        mag_low_since = millis();
      }
      if (!mag_low && mag_was_low && usrConf.mag_mode == 0)
      {
        // Legacy SW33b tap→BLE-session/dot toggle. Gated to mag_mode==0: only runs when the magnet
        // is NOT being used as the FM/RTM gesture input, so the two inputs can never collide.
        uint32_t held_ms = millis() - mag_low_since;
        if (bt_dot_state == BT_DOT_FAST)
        {
          bt_dot_state = BT_DOT_OFF;
        }
        else if (held_ms >= 5000)
        {
          bt_dot_state = BT_DOT_FAST;
        }
        else if (held_ms >= 400)
        {
          bt_dot_state = (bt_dot_state == BT_DOT_OFF) ? BT_DOT_SLOW : BT_DOT_OFF;
        }
      }
      // With mag_mode>0 the magnet no longer owns the dot. Reflect the real BLE state instead:
      // BT_DOT_SLOW (the "advertising/on" indication used by Init.ino for bt_enabled==2) when BLE
      // is up via the always-on setting or the boot gesture, otherwise OFF. This is re-derived every
      // poll from config, never from a magnet edge, so the gesture can never change it.
      if (usrConf.mag_mode > 0)
      {
        bt_dot_state = (usrConf.bt_enabled == 2 || bt_session_forced) ? BT_DOT_SLOW : BT_DOT_OFF;
      }
      mag_was_low = mag_low;
    }
  }

  // V2.5-Evo - 2026-07-20 - MagGesture: magnet arm gesture. Runs AFTER the SW33b block above
  // so it sees an up-to-date mag_seen_high. It only reads P_MAG and mag_seen_high — it never
  // writes bt_dot_state, so the BT status dot behaves exactly as before.
  // Called from loop() (not a task) because it can call the blocking RTM/FM arm entry points.
  runMagGesture();

  checkSerial();
  // V2.5-Evo - 2026-07-20 - BLE re-enable deep-fix (Rex §4.5): the BLE telemetry push was moved OUT of
  // loop() into the dedicated Core-0 bleNotifyTask (spawned by bleInitTask after a successful init), so
  // that BLE cadence can never extend the same loop iteration that renders the display. Nothing BLE-
  // related runs here anymore; loop() timing (and thus GPS meta ≥2 Hz + RTM/FM cadence) is protected.

  // Update last_user_input_ms when intentional input is detected.
  // Throttle threshold: thr_scaled > 20 (~8% pull — above noise floor).
  // Toggle threshold: steer_scaled moved > 15 counts from centre (127) — deliberate movement.
  // Both thresholds are chosen to reject pocket pressure and ADC noise.
  if (thr_scaled > 20 || abs((int)steer_scaled - 127) > 15)
  {
    last_user_input_ms = millis();
  }
  last_sleep_steer = steer_scaled;

  // Auto-sleep: fires when EITHER condition is true for sleep_timeout_s seconds.
  // Primary:  no intentional user input (throttle or toggle above deadzone).
  // Fallback: no LoRa packet received from RX (RX off or out of range).
  // Both use the same timeout. sleep_timeout_s == 0 disables auto-sleep entirely.
  // Pocket-safe: thr_scaled ≤ 20 and steer within 15 counts of centre do not count as input.
  if (usrConf.sleep_timeout_s > 0)
  {
    uint32_t sleep_ms   = (uint32_t)usrConf.sleep_timeout_s * 1000UL;
    bool     user_idle  = (millis() - last_user_input_ms > sleep_ms);
    bool     rx_silent  = (millis() - last_packet        > sleep_ms);
    if (user_idle || rx_silent)
    {
      deepSleep();
    }
  }

  // V2.5-Evo - 2026-04-27 - P8: Show RTM/FM info (distance/speed) when RTM is active; normal display otherwise
  if (rtm_tx_active)
    renderRtmInfoDisplay();
  else
    renderOperationalDisplay();
  
  //delay(110);
  vTaskDelay(pdMS_TO_TICKS(110));

} //End of loop()

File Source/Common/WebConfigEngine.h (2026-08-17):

#ifndef WEB_CONFIG_ENGINE_H
#define WEB_CONFIG_ENGINE_H

#ifdef WIFI_ENABLED

// Shared web config AP and HTTP API for BREmote V2 TX and RX.
// V2.5-Evo - 2026-08-17 - SAFETY: the web portal's Base64 config import now runs cfgValidateCrossField() as well as validateConfig(), which every other intake path (?setconf, the SPIFFS boot loader, ?set, cfgSetBatch, the legacy-migration branch) already did. It was the only path that did not, and validateConfig() checks each field against its own range in isolation - so a blob with PWM0_min = 2500 and PWM0_max = 500, both individually legal, was accepted and inverted the throttle map into a constant full-throttle output at every throttle position including zero. Called before validateConfig() and on the staging copy, matching every other path, so the validator's auto-corrections are what gets range-checked and written. Existing ERR_IMPORT_VALIDATION_FAILED reused with the reason in the existing detail field. No confStruct change, no new error code, both boards.
// V2.5-Evo - 2026-08-17 - the web portal's Base64 config import now accepts a legacy backup on the same terms ?setconf does: a blob that is the one older SW version whose confStruct is a byte-exact prefix of this one is migrated instead of refused with ERR_IMPORT_INVALID_SIZE. It calls the SAME cfgBlobIsMigratableLegacy() / cfgMigrateLegacyBlob() helpers the serial path calls, so the two importers cannot disagree about which bytes go where. Everything that is not that exact (size, version) pair takes the identical path, and gets the identical error, it does today. Inert on the TX (compile-time constant is false there). No confStruct change.
// V2.5-Evo - 2026-07-25 - STAGE 0 PART B (RX only, inside ENABLE_WEB_LOG_DOWNLOAD — TX never compiles this block): the WiFi log download now reads the 8-byte self-describing log header before sending anything, steps records by header.record_size instead of sizeof(VescLogData), emits the CSV column header matching the level the file was actually recorded at, and rejects a header-less/old/corrupt file with a JSON error rather than a half-sent body. Row formatting moved to the single shared logFormatCsvRow() in BREmote_V2_Rx.h that the serial ?download path also calls, so the two CSV outputs can no longer drift apart. No TX impact, no confStruct change.
// V2.5-Evo - 2026-07-25 - F-WEBCSV: WiFi log download resynced to the serial ?download CSV (26->31 columns); ERPM x10 scaling and duty_cycle cast now match Logger.ino; row buffer 400->512
// V2.5-Evo - 2026-05-03 - Content-Disposition header on export (iPhone filename fix)
// V2.5-Evo - 2026-05-08 - Bundle 1: HTTP log download updated for 26-column CSV (+heading_error_dx10, d_error_dx10)
// V2.5-Evo - 2026-05-06 - FIX-LOGDL-1: log download CSV updated for LOG-EXT-1 fields (24 columns); WDT reset + FreeRTOS yield added inside read loop to support files >40KB without AP reboot

// Forward declarations — defined per-side in WebConfig.ino.
extern const char* WEB_CFG_AP_SSID;
extern const char* WEB_CFG_SHUTDOWN_REASON;
void webCfgResetCalibration(confStruct& conf);

// Forward declarations for functions defined later in this header.
String webCfgGetStateLine();
String webCfgGetLastError();

// ===== Internal State =====

static WebServer webCfgServer(80);
static const uint8_t WEB_CFG_DBG_OFF = 0;
static const uint8_t WEB_CFG_DBG_SOME = 1;
static const uint8_t WEB_CFG_DBG_FULL = 2;
static bool web_cfg_ap_started = false;
static bool web_cfg_ap_had_client = false;
static bool web_cfg_should_shutdown = false;
static uint8_t web_cfg_last_station_count = 0;
static uint32_t web_cfg_ap_started_at_ms = 0;
static String web_cfg_last_shutdown_reason = "";

// ===== Helpers =====

static void webCfgStopService(const char* reason)
{
  if(!web_cfg_ap_started) return;
  web_cfg_last_shutdown_reason = reason ? String(reason) : String("unknown");
  webCfgServer.stop();
  WiFi.softAPdisconnect(true);
  WiFi.mode(WIFI_OFF);
  web_cfg_ap_started = false;
  web_cfg_service_enabled = false;
  Serial.print("Web config AP stopped. Reason: ");
  Serial.println(web_cfg_last_shutdown_reason);
}

static const char* webCfgMethodName(HTTPMethod method)
{
  switch(method)
  {
    case HTTP_GET: return "GET";
    case HTTP_POST: return "POST";
    case HTTP_PUT: return "PUT";
    case HTTP_PATCH: return "PATCH";
    case HTTP_DELETE: return "DELETE";
    case HTTP_OPTIONS: return "OPTIONS";
    default: return "OTHER";
  }
}

static bool webCfgDebugEnabledFor(bool importantOnly)
{
  if (web_cfg_debug_mode == WEB_CFG_DBG_OFF) return false;
  if (web_cfg_debug_mode == WEB_CFG_DBG_FULL) return true;
  return importantOnly;
}

String webCfgGetDebugModeName()
{
  if (web_cfg_debug_mode == WEB_CFG_DBG_FULL) return "full";
  if (web_cfg_debug_mode == WEB_CFG_DBG_SOME) return "some";
  return "off";
}
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

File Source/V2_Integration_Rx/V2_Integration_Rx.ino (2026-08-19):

// *** LATEST: V2.5-Evo - 2026-07-25 - STAGE 0 (instrumentation only): loop() body wrapped in diagLoopBegin()/diagLoopEnd() so ?diag and the level-4 log record can report loop min/mean/max time. Cycle-counter based (~5 ns), measured before the existing vTaskDelay so the deliberate 10 ms sleep is not counted as work. No control-path statement added, removed or reordered; no confStruct change; SW_VERSION stays 34 ***
// V2.5-Evo - 2026-07-19 - P3 FM — runFmLoop() added to loop() after runRtmLoop(); Follow-Me autonomous following (see RTMState.ino). No confStruct change; SW_VERSION stays 33
// V2.5-Evo - 2026-06-04 - D1 — UART-mux read-back verify (setUartMux); skip VESC poll while throttle high; no confStruct change
// V2.5-Evo - 2026-05-14 - SW55 — GPS yields MUX to VESC on exit; rcv_err removed from receiveFromVESC; boot MUX starts on VESC
// V2.5-Evo - 2026-05-11 - Telemetry Fix: VESC moved to its own vesc_loop_timer (2Hz); checkButtons() added to loop() for runtime BIND compass cal
// V2.5-Evo - 2026-05-03 - Removed commented-out SPIFFS.remove dead code (LOW audit cleanup)
// V2.5-Evo - 2026-04-30 - Bundle E: GPS moved to its own gps_loop_timer (rate = gps_update_hz); removed from 1000ms gate
// V2.5-Evo - 2026-04-25 - P7: Added runRtmLoop() call in loop(); forward declarations
#include "BREmote_V2_Rx.h"

SX1262 radio = new Module(P_LORA_NSS, P_LORA_DIO, P_LORA_RST, P_LORA_BUSY);
Adafruit_AW9523 aw;
Ticker ticksrc;
TinyGPSPlus gps;

// V2.5-Evo - 2026-04-25 - P7: RTM state machine and compass heading function
void runRtmLoop();
float getCompassHeading();
// V2.5-Evo - 2026-07-19 - P3 FM: Follow-Me state machine (RTMState.ino)
void runFmLoop();
// V2.5-Evo - 2026-08-18 - LATCH-1: restore a heading-disagreement verdict that outlived a reboot.
// File-scope static in RTMState.ino; Arduino compiles the sketch as one translation unit, so this
// declaration is what makes the call legal — the same pattern headingDisagreeLatched() already uses.
static void headingDisagreeRestore();

void setup()
{
  enterSetup();

  initHardware();
  initStorage();
  
  // ---> NEW: Initialize the QMC5883L Compass <---
  initCompass();

  // V2.5-Evo - 2026-08-18 - LATCH-1. After initStorage() has mounted SPIFFS and after the compass
  // has reported itself, so the boot log reads in the right order: which compass is fitted, then
  // whether there is a standing verdict against it. Must precede initTasks() — the verdict has to
  // be in place before anything can arm.
  headingDisagreeRestore();

  runBootSequence();
  initTasks();
  initWatchdog();

  // Initialize the logger task and memory mutex
  initLogger();
  if (usrConf.logger_en == 1) {
    startLog();
  }

  exitSetup();
  PWM_active = 1;
}

unsigned long loop_timer = 0;
unsigned long gps_loop_timer  = 0;  // V2.5-Evo - 2026-04-30 - Bundle E: separate GPS polling timer
unsigned long vesc_loop_timer = 0;  // V2.5-Evo - 2026-05-11 - Telemetry Fix: separate VESC polling timer (2Hz)
int wetness_counter = 0;

void loop()
{
  // V2.5-Evo - 2026-07-25 - STAGE 0 (instrumentation only): stamp the CPU cycle counter on the
  // first line and close the measurement on the last line of the body, BEFORE the vTaskDelay
  // below — so what gets recorded is the WORK this pass did, not the 10 ms it deliberately
  // sleeps afterwards. esp_cpu_get_cycle_count() is a single CSR read (~5 ns); micros() would
  // cost ~1 us, the same order as the thing being measured. Nothing between these two lines is
  // changed, reordered, added or removed.
  const uint32_t diag_loop_c0 = diagLoopBegin();

  esp_task_wdt_reset();
#ifdef WIFI_ENABLED
  webCfgLoop();
#endif
  checkSerial();
  
  // Process Logger LED and button in main thread (AW9523 I2C is not ISR-safe)
  loggerLoop();

  // Runtime button detection: BIND = compass cal. Boot-time pairing is guarded inside.
  checkButtons();

  // V2.5-Evo - 2026-04-25 - P7: RTM state machine — safety gates, steering override, Phase C.
  // Runs at 10Hz regardless of the 1000ms GPS/VESC gate below.
  runRtmLoop();

  // V2.5-Evo - 2026-07-19 - P3 FM: Follow-Me state machine — activation conditions, trailing
  // target-point steering, throttle cap chain. Also rate-limits itself to 10Hz internally.
  // MUST run after runRtmLoop(): RTM and FM are mutually exclusive and runFmLoop() reads
  // rtm_rx_active to decide whether RTM already owns the buggy this tick. FM keeps its own
  // throttle cap (fm_throttle_cap) rather than sharing rtm_approach_cap, so RTM's per-tick
  // "inactive -> cap 255" housekeeping can never transiently clear an FM cap in between.
  runFmLoop();

  // GPS runs on its own configurable-rate timer, independent of the 1000ms VESC/wetness gate.
  // gps_update_hz=2 → 500ms interval; gps_update_hz=5 → 200ms interval.
  // Guard against zero (divide-by-zero): fall back to 500ms if gps_update_hz is unset.
  if(usrConf.gps_en)
  {
    uint32_t gps_interval_ms = (usrConf.gps_update_hz > 0) ? (1000UL / usrConf.gps_update_hz) : 500UL;
    if(millis() - gps_loop_timer >= gps_interval_ms)
    {
      gps_loop_timer = millis();
      getGPSLoop();
    }
  }
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

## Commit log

2026-04-22 V3.0.0 initial commit - GPS implementation, chip type support, 7 critical bug fixes
    [AllPartsSliced_V2-1.3mf, Assy_Clamp.stl, BotShieldV2-4_BOM.xlsx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]
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2026-04-22 Fix C1 critical mutex gap in VESC.ino, fix I2/I3 System.ino debug WDT, fix I1 Logger comment, remove AFM/Gemini comments
    [Logger.ino, System.ino, VESC.ino]
2026-04-22 Remove all remaining AFM/Gemini comment labels across TX, RX, and Common
    Replace attribution markers with neutral V3 comments describing actual behavior.
    Remove dead commented-out esp_task_wdt_reset() lines in TX tasks (TX uses
    native Core WDT; these were intentionally disabled and the labels were the
    only remaining reference to the old toolchain session).
    [Analog.ino, BREmote_V2_Rx.h, BREmote_V2_Tx.h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]
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2026-04-22 feat(TX): add GPS status dot at C7 R0 in updateBargraphs(); fix digit-clear mask
    [Display.ino]
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2026-04-22 feat(TX): P4 signal-drop haptic — Pattern A when sq_graph drops to 1 while connected
    - Add edge-detection locals (last_sq, sq_warned, last_con) to vibrationTask()
    - Fire Pattern A (2 Short) when sq_graph transitions from >1 to 1 while connected
    - Guard against failsafe blink cycle (sq_graph 0↔1 artifact) via is_connected gate
    - Seed last_sq on reconnect to suppress spurious edge; sq_warned prevents spamming
    [System.ino]
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2026-04-24 fix(TX/GPS): call initTxGPS() in setup() after checkCharger(); add ?printgps ?gpsraw ?gpsreinit diagnostics
    [V2_Integration_Tx.ino]
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2026-04-25 feat(RX): Priority 6 — Phase B GPS handshake anti-spoofing
    gpsPhaseBCheck() runs on first 0xF3 meta-packet + every 30s.
    Distance check: TX-RX Haversine > gps_max_pair_dist_m → fail.
    Speed check: |TX_speed - RX_speed| > gps_max_speed_diff_kmh → fail.
    gps_phase_b_ok flag (false = RTM arming blocked).
    sizeof(confStruct) 128→136; first flash resets SPIFFS to defaults.
    2 new SPIFFS params added to confStruct, ConfigService, WebUI.
    [BREmote_V2_Rx.h, ConfigService.ino, GPS.ino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]
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2026-04-25 fix(RX/GPS): use isValid() not isUpdated() for speed check in getGPSLoop() — isUpdated() blocked Phase B when stationary
    [GPS.ino]
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2026-04-25 fix(RX/P7): remove duplicate VESC_MORE_VALUES define; update JSON reference comment with P7 fields
    [BREmote_V2_Rx.h]
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2026-04-25 fix(RX/P7): change RTM volatile globals to std::atomic for cross-core safety
    generatePWM() runs on core 0; RTMState.ino loop() will run on core 1.
    volatile alone gives no memory barrier on Xtensa dual-core; std::atomic
    provides seq_cst, matching the existing rfInterrupt pattern.
    [BREmote_V2_Rx.h]
2026-04-26 fix(RX/P7): return -1.0f on I2C failure in getCompassHeading()
    readCompassRaw() returns bool; ignoring it meant stale magX/magY could
    produce a silent wrong heading on any I2C glitch.
    [Compass.ino]
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2026-04-26 fix(TX/P7): promote rtm_hold_start to file scope to prevent stale arm
    Static inside a switch case can't be reset from setRtmArmed(). If arm
    window expires with throttle held, stale hold_start caused immediate
    ACTIVE on next arm. Reset in setRtmArmed() now resolves this.
    [RTMState.ino]
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2026-04-26 fix(RX/P7): 4 compile errors + CRITICAL defaultConf rtm_stop_distance_m
    Compile fixes (from Claude.ai session):
    1. PWM.ino: add (uint8_t) cast on rtm_steer_override to resolve ternary
    type mismatch (std::atomic<uint8_t> vs volatile uint8_t)
    2. RTMState.ino: add extern bool gps_phase_b_ok; (defined in Radio.ino)
    3. BREmote_V2_Rx.h: add rtm_stop_distance_m field to confStruct (fills
    former 2-byte tail padding; sizeof stays 152; static_assert updated)
    4. ConfigService.ino: add rtm_stop_distance_m to kCfgFields[]
    CRITICAL safety fix (found in security review 2026-04-26):
    - defaultConf.rtm_stop_distance_m was missing from the initializer list.
    C++ zero-init would set it to 0, making Gate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
    [BREmote_V2_Rx.h, ConfigService.ino, PWM.ino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]
2026-04-27 fix(TX/P8): resolve 3 compile errors - assert size 126→124, extern current_vib_pattern
    - static_assert updated 126→124: 3 new P8 uint16_t fields add 6 bytes to 118
    bytes of existing data = 124 bytes; 124 % 4 == 0 so no tail padding (comment
    in P8 block was wrong — corrected to match reality)
    - Added extern volatile uint8_t current_vib_pattern at top of RTMState.ino;
    fixes "not in scope" errors on lines 48 and 63 (defined in System.ino:719)
    [BREmote_V2_Tx.h, RTMState.ino]
2026-04-27 fix(TX/P8): combo gestures never fire — tap window 100ms→500ms (COMBO_TAP_MAX_MS)
    Root cause: tap detection used `held_ms < gear_change_waittime` (100ms from
    pushtime, set after a 50ms initial delay = ~150ms total from button press).
    Any RIGHT press over ~150ms total was silently dropped — last_tap_dir was never
    set to +1, so `has_combo` was always false, and every LEFT hold fired the simple
    2s display-cycle instead of the 5s RTM combo.
    Fix: add COMBO_TAP_MAX_MS = 500UL constant, decoupled from gear_change_waittime.
    A tap up to 500ms now primes the combo correctly. A tap of 100–500ms also fires
    a gear/cap change as a side effect (gear_change_waittime still = 100ms), which is
    accepta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
    [Hall.ino]
2026-04-27 fix(TX/P8): restore correct gesture map - right=display, left=lock, combos unchanged
    P8 had simple LEFT hold → display cycle and RIGHT hold → no action. Both wrong.
    Corrected to match confirmed gesture spec:
    - RIGHT hold 2s: cycleDisplayMode(1) [was no-op]
    - LEFT hold 2s: system_locked=1 + displayLock() [was cycleDisplayMode, now restored]
    - RIGHT tap + LEFT hold 5s: RTM arm (unchanged)
    - LEFT tap + RIGHT hold 5s: FM cycle (unchanged)
    - COMBO_TAP_MAX_MS = 500ms (unchanged from previous fix)
    no_lock config flag respected: LEFT hold 2s only locks when usrConf.no_lock == 0.
    runMenu() lock/unlock path was already intact in P8 and requires no changes.
    Lines changed in handleGearT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
    [Hall.ino]
2026-04-27 feat(TX/P8.1): FM UX redesign — arm/disarm toggle, mode memory, arm window
    FM is now a stateful arm/disarm toggle instead of a one-shot mode cycle.
    ARM (LEFT tap + RIGHT hold 5s):
    - Arms at last_fm_mode (RAM, defaults F1 on power cycle)
    - Blinks "F[mode]" x2 on display; fires Pattern 4 (2 fast buzzes)
    - Sends 0xF2 + mode to RX
    CHANGE MODE while armed (LEFT hold 2s, intercepted before lock):
    - cycleFmModeArmed(): cycles F0→F1→F2→F3→F0, stays armed, resets arm timer
    DISARM (any of):
    - Same combo again (toggle) → cycleFmMode() with fm_armed==true → fmDisarm()
    - Gate 1: throttle release for 3s after first engagement
    - Arm-window: fm_arm_window_s (SPIFFS, 10-60s, de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
    [BREmote_V2_Tx.h, ConfigService.ino, Hall.ino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]
2026-04-27 fix(TX/P8): no_lock boot state + FM display FM0-FM3
    Bug 1: Init.ino applyConfigSettings() was unconditionally setting
    system_locked=0 on every boot, making no_lock=0 (locking enabled)
    ineffective. Now conditional: no_lock=1 boots unlocked, no_lock=0
    boots locked and requires manual gesture to unlock.
    Bug 2: FM mode display showed only "F" because digit "1" (and other
    small modes) as the second character of displayDigits() renders as a
    single thin horizontal bar — nearly invisible next to the "F" glyph.
    Replaced all FM mode display calls with scroll3Digits(LET_F, LET_M,
    mode, 50) which clearly scrolls "FM0"/"FM1"/"FM2"/"FM3" across the
    display (~700ms per scroll).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
    [Init.ino, RTMState.ino]
2026-04-28 refactor(TX): rename rtm_stop_distance_m → rtm_disengage_distance_m
    Parameter rename only — no behavior change. RX rtm_stop_distance_m
    unchanged. Updated all TX-side references:
    - BREmote_V2_Tx.h: confStruct field + defaultConf comment
    - ConfigService.ino: SPIFFS field table key
    - WebUiEmbedded.h: web UI key, label, description
    - README.md: TX SPIFFS table (also corrects default 3→10)
    - CLAUDE.md: Priority 8 notes
    [BREmote_V2_Tx.h, ConfigService.ino]
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2026-04-28 feat(p9): BREmote V2.5-Evo — safety fixes, full-screen confirms, R5 bar, dist_unit, rename
    RX RTMState.ino:
    - Bug 1A: Gate 9 zero-guard (rtm_stop_distance_m==0 from stale SPIFFS → fallback 3m)
    - Bug 1B/1C: always-compute telemetry.rtm_distance before gates so TX has data pre-arm
    TX RTMState.ino:
    - Bug 1D: Pattern 4 + "St P" centralised in rtmDisengage() — all exit paths now confirm
    - Pre-arm distance check (Bug 1B): rejects activation if already within disengage distance
    - "A rM" full-screen flash on both ACTIVE transitions; rtm_arm_dist_m captured for R5 bar
    - FM: cycleFmMode/cycleFmModeArmed/fmDisarm use showFullScreenMessage(); showFmMode() removed
    - fm_armed changed from static to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
    [BREmote_V2_Rx.h, BREmote_V2_Tx.h, ConfigService.ino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]
2026-04-28 fix(display): correct fontCompact3x7 bit order for 9 chars, replace FL with 100 at full cap
    [Display.ino]
2026-04-29 chore(display): remove boot self-test, restore fast startup
    Also includes Display.ino + RTMState.ino bug fixes from this session:
    - Bug1: showFullScreenMessage() save+reassert R6 to beat updateBargraphs() FreeRTOS task
    - Bug2: setRtmArmed() clears fm_armed — RTM and FM are mutually exclusive
    - Bug3: rtmDisengage() clears displayBuffer[6] (R5); dead FM stub removed from updateR5ProximityBar()
    - Bug4: runDoubleSqueezeArm() rewritten — single+double squeeze unified, "A r" removed, RTM_ARMED dead code
    - Bug5: fc3x7_r + fc3x7_n bitmaps corrected 0x7C→0x1E to render R1-R4, avoid R5
    [BREmote_V2_Tx.h, ConfigService.ino, Display.ino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]
2026-04-29 fix(rtm): GPS timeout x4 override during arm ceremony, FM cycling fixes, RTM arm stage 1 animation
    [RTMState.ino]
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2026-04-29 Fix 6-1 + 6-2: RX uses usrConf.tx_gps_stale_timeout_ms; Phase B auto-expires on TX GPS drop
    [RTMState.ino]
2026-04-29 Fix 4-3 + 2-1: fm_armed volatile; clear gps_timeout_override on pre-arm rejection
    Also updates Display.ino extern declaration to volatile to match definition.
    [Display.ino, RTMState.ino]
2026-04-29 Fix 4-1: vibrationTask stack 2048 words, handle saved, added to ?printtasks output
    [BREmote_V2_Tx.h, Init.ino, System.ino]
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2026-04-30 Fix: RTM arm always failed — BugA zero-init distance false rejection, BugB Serial1 GPS drain before RTM_ACTIVE
    [BREmote_V2_Tx.h, RTMState.ino]
2026-04-30 fix(tx/rtm): RTM arm always failed — two root causes fixed
    BugA: decodeRtmDistanceM() returned 0.0m for zero-initialized telemetry
    (d==0x00 before first RX packet). Pre-arm check saw 0.0m ≤ disengage
    threshold and rejected the arm. 0x00 now returns -1.0f (no data), same
    as 0xFF.
    BugB: GPS age exceeded 4× override threshold after double-squeeze
    ceremony. loop() suspended for 7-10s; gps_tx.location.age() accumulated
    past rtm_gps_timeout_ms×4=8000ms. Gate 2 fired on first runRtmLoop()
    call. Fix: drain Serial1 NMEA backlog (300ms cap) immediately before
    RTM_ACTIVE to refresh age to near-zero.
    [RTMState.ino]
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2026-04-30 Sleep: dual-condition auto-sleep — user idle OR RX silent
    Replaces single last_packet check with OR logic: fires when either
    no intentional user input (thr_scaled > 20 or steer > 15 counts from
    centre) OR no LoRa packet from RX exceeds sleep_timeout_s. Pocket-safe
    thresholds reject ADC noise and accidental contact. last_user_input_ms
    and last_sleep_steer track input state; both conditions use the same
    SPIFFS sleep_timeout_s value.
    [V2_Integration_Tx.ino]
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2026-04-30 BundleA: radio_preset max 3→2 (prevents boot halt); dead foil_speed != 99 sentinel removed
    [ConfigService.ino, Radio.ino]
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2026-04-30 BundleC: log startTransmit() errors on TX (6 sites) and RX (2 sites) — observability only
    [Radio.ino]
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2026-04-30 Fix: WebUI auto-reinstall via FNV1a hash — WEB_UI_VERSION date string removed; never stale again
    [SPIFFSEngine.h]
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2026-04-30 RTM re-arm fix + approach decel zone (rtm_approach_zone_m)
    - Gate 9 clean disengagement: rtm_rx_active=false, no emergency stop, seamless manual handoff
    - Re-arm unblocked: telemetry.rtm_distance=0xFF when RTM inactive, TX pre-arm check bypassed
    - Approach decel zone: linear throttle ramp from rtm_approach_zone_m (15m default) down to 0 at rtm_stop_distance_m
    - New SPIFFS param rtm_approach_zone_m (0-100m, default 15m); sizeof confStruct 156→160
    - SW_VERSION bump needed after this commit — first flash resets RX SPIFFS to defaults
    [BREmote_V2_Rx.h, ConfigService.ino, PWM.ino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]
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2026-05-02 feat: fm_display_mode SPIFFS field; FM center-expanding R5 bar; RX distance fixes B/C/D; add proximity bar GIFs
    - TX: thr_expo1 repurposed as fm_display_mode (1=TX speed, 2=dist, 3=buggy speed, 4=throttle%)
    - TX: FM R5 bar center-expanding from C4+C5 (replaces linear fill)
    - TX: lazy-capture rtm_arm_dist_m on first valid render if missed at arm time (Fix A)
    - RX: encode rtm_distance always when both GPS valid — feeds FM bar + pre-arm block (Fix B)
    - RX: FM bar keep-last-known on GPS dropout; 0xFF only if TX GPS never received (Fix C)
    - RX: gps_tx_ok relaxed for FM/idle; never reset rtm_distance to 0xFF when RTM inactive (Fix D)
    - docs: add rtm_bar_animation.gif and fm_bar_animation.gif
    - f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
    [BREmote_V2_Tx.h, ConfigService.ino, Display.ino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]
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2026-05-03 TX GPS init decoupled from speed_src — Phase B anti-spoofing always active when gps_en=1 (M1 audit fix)
    [GPS.ino]
2026-05-03 RX gps_tx_ok: replace 0.0 sentinel with timestamp age check — fixes stale GPS accepted indefinitely (C1+M2 audit fix)
    [RTMState.ino]
2026-05-03 TX displayError() clamp corrected 29→33 — errors 30–33 now display correctly (H6 audit fix)
    [Display.ino]
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2026-05-03 RX Logger: deleteCandidates String[]→char[][] heap fix + active-file guard in deleteLogFile() (H4)
    [Logger.ino]
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2026-05-06 fix(RX): drain Serial1 RX buffer in getVescLoop() before VESC query
    Serial1 is shared between GPS and VESC via AW9523 analog mux. After mux
    switch, stale partial-NMEA bytes in the RX buffer prefixed VESC responses
    and corrupted frame parsing in receiveFromVESC(), causing pkt_age_ms to
    grow unboundedly and last_uart_packet to never update. Verified by ?vescping.
    Non-blocking while(Serial1.available()) drain added after 10ms mux-settle
    delay, before Serial1.flush() (TX-side only).
    [VESC.ino]
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2026-05-06 feat(RX): D2+D3 — compass snapshot globals + RTM heading-source SPIFFS fields (SW29)
    D2 (Compass.ino): add compass_snapshot_heading/ms globals and
    updateCompassSnapshot() — captures clean compass heading during motor-idle
    for future RTM steering. Function defined but not yet called (D5 wires it in).
    D3 (BREmote_V2_Rx.h): add rtm_use_compass (0=COG only, 1=hybrid, 2=compass
    diag) and rtm_cog_min_speed_kmh SPIFFS fields. 2x uint8_t fill existing tail
    padding — sizeof(confStruct) stays 160. SW_VERSION 28→29 triggers SPIFFS
    reset on first flash; re-pair, re-configure, re-run runcal after flashing.
    [BREmote_V2_Rx.h, Compass.ino]
2026-05-06 fix(RX): D3-Fix — rtm_use_compass/cog_min_speed_kmh uint8_t→uint16_t (SW30)
    ConfigService engine only supports CFG_U16; uint8_t fields would have been
    unreadable by ConfigService and WebUI. Changing to uint16_t matches all other
    SPIFFS-pipelined small-range fields in the project. sizeof(confStruct) 160→164;
    SW_VERSION 29→30 triggers SPIFFS reset on first flash.
    [BREmote_V2_Rx.h]
2026-05-06 feat(RX): D4 — register rtm_use_compass + rtm_cog_min_speed_kmh in ConfigService
    Adds CFG_U16 entries to kCfgFields[] so ?conf, ?get, ?set, and web UI
    form validation work for the two D3 heading-source fields.
    Ranges: rtm_use_compass 0-2, rtm_cog_min_speed_kmh 1-15 km/h.
    SW_VERSION unchanged (30); struct unchanged; no SPIFFS reset.
    [ConfigService.ino]
2026-05-06 fix(RX): D5 — layered RTM heading source; fixes compass EMI vulnerability
    getRtmHeading(): GPS COG primary (HIGH conf), compass snapshot fallback
    at low speed (MEDIUM/LOW conf), hold-straight when no source (NONE).
    updateRtmSteering(): uses getRtmHeading() instead of compass-only; LOW
    confidence reduces steering authority 50% to prevent oscillation.
    Gate 6: accepts any valid heading source, not just compass.
    runRtmLoop(): updateCompassSnapshot() called before rate-limit gate so
    clean idle headings are captured regardless of RTM state.
    Bench data: compass swings 100°+ at 20% throttle. COG unaffected by
    motor EMI. Hybrid mode (default rtm_use_compass=1) is the safe path.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
    [RTMState.ino]
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2026-05-06 feat(TX/RX): gesture fix, digit cache, dirty-save WebUI, ?vescraw probe
    TX Hall.ino — FIX-GESTURE-1: COMBO_TAP_MAX_MS 500ms→1000ms
    In no_gears mode the 100ms display cycle caused ~70% of RTM arm attempts
    to hit the LOCK branch instead. 1s tap window gives clean 1s separation
    from the 2s non-combo long-press threshold.
    TX Display.ino — 30s digit cache for foil_temp/foil_bat
    Brief VESC UART silences no longer flash '--' on the digit display.
    getEffectiveFoilTemp/Bat() hold last-known value for 30s; bargraph blink
    remains the 'no live data' indicator.
    TX Display.ino — PV mode renders X.Y kW with decimal point
    foil_power byte → kW×10 → decimal dot at C3R4.
    TX WebUiE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
    [Display.ino, Hall.ino, System.ino]
2026-05-07 feat(TX): DIAG — keep GSV sentences, add ?gpscoldreset UBX cold-restart command
    GPS.ino: comment out GPGSV/GPGLL/GPVTG disable writes in both BN-220 and M10
    init paths so GSV (satellites in view) remains visible during fix-acquisition
    troubleshooting. Add txGpsColdReset() which sends UBX-CFG-RST (bbr_mask=0xFFFF,
    mode=0x02) to force the GPS module to discard all cached data and reacquire.
    System.ino: wire ?gpscoldreset serial command to txGpsColdReset(). Useful when
    GPS appears stuck (PPS LED firing but no valid NMEA fix in ?gpsraw output).
    Checksum note: CK_A=0x0E/CK_B=0x61 verified correct for reset_mode=0x02.
    [GPS.ino, System.ino]
2026-05-07 fix(TX): GPS.ino FIX-GPS-1 dual-baud init + update SW26 binary to clean build
    GPS.ino includes the dual-baud init fix (FIX-GPS-1) that handles both GPS
    startup states (factory 9600 and retained 115200), preventing UART RX lockout
    from the frame-error threshold. SW26 binary now reflects all current source
    changes (DIAG + FIX-GPS-1). Previous SW26 binary was built from stale cache
    and did not include the source changes.
    [GPS.ino]
2026-05-07 FIX-LOGDL-2: serial ?download supports LOG-EXT-1 fields, WDT-safe for large files
    downloadLogFile() in Logger.ino:
    - CSV header extended from 12 to 24 columns (all LOG-EXT-1 heading-debug fields)
    - Serial.printf updated to format all 24 VescLogData fields
    - esp_task_wdt_reset() added at top of read loop; delay(1) every 50 records
    to yield FreeRTOS — fixes confirmed WDT crash at ~3min/~350KB
    Column order and format specifiers match FIX-LOGDL-1 (WebUI HTTP path) so
    both download paths produce byte-identical CSVs.
    [Logger.ino]
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2026-05-07 FIX-LOGDL-1: WebUI HTTP /api/logs/download supports LOG-EXT-1 fields (24 cols); WDT-safe for large files (>40KB)
    [WebConfigEngine.h]
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2026-05-08 Bundle 1: RTM/FM steering preset system (P+D + bearing filter)
    - Add rtm_steer_response SPIFFS field (0-4 preset index, default 2 = Normal)
    - Replace dummy_delete_me in-place; sizeof(confStruct) unchanged at 164
    - SW_VERSION 30→31 (forces SPIFFS reset to apply Normal default)
    - 5 presets: Very Soft / Soft / Normal / Sharp / Very Sharp
    - Each preset = {error_clamp_deg, Kp, Kd, target_filter_tau_s}
    - P+D math + low-pass filter on TX target position (FM path-following)
    - Filter τ varies 0.5s (Sharp) to 5.0s (Very Soft) — surfer wobble suppression
    - 2 new diagnostic log fields: heading_error_dx10, d_error_dx10 (CSV cols 25/26)
    - FM placeholder field comments (zone_angle_*, near_diag_*) impr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
    [BREmote_V2_Rx.h, ConfigService.ino, Logger.ino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]
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2026-05-09 Bundle 9-Final: USB CDC On Boot guard + arduino-cli fqbn fix; revert TEMP-DIAG-1
    - Revert TEMP-DIAG-1 manual GPIO 19 toggle from V2_Integration_Tx.ino setup()
    - Add #error guard to TX and RX headers: fails compile if ARDUINO_USB_CDC_ON_BOOT
    is enabled. Catches wrong board config at compile time, prevents silent GPS
    failure mode (ESP32-C3 USB peripheral claims GPIO 18/19, Serial1 silently fails)
    - Update CLAUDE.md Section 17 arduino-cli fqbn from
    esp32:esp32:esp32c3 to esp32:esp32:esp32c3:CDCOnBoot=default
    ensures Claude Code compiles match Andres's Arduino IDE setting (Disabled)
    - Documented in BREmote_V2_*.h headers: required IDE setting + alternate
    arduino-cli fqbn parameter; deb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
    [BREmote_V2_Rx.h, BREmote_V2_Tx.h]
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2026-05-10 Safety fix: zero rtm_thr_cap_tx during RTM arm ceremony (TX SW26)
    sendData() FreeRTOS task runs every 100ms while loop() blocks in
    runDoubleSqueezeArm(). With cap=255 (prior state), live arm-squeeze
    bytes drove the motor at full duty with rtm_rx_active=0 (no RX gate
    suppression). Fix: cap=0 at ceremony start; restored on all 3 abort
    paths; success path leaves cap=0 so calcRtmThrottleCap() ramp takes
    over on first RTM_ACTIVE tick. Covers single- and double-squeeze.
    Confirmed in field log 050926_223439: 11s motor runaway at 96% duty.
    Also: docs/Compass_Cal_Analysis.md (field test log review, compass
    EMI and calibration notes); .gitignore excludes CLI_compile_export.md.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
    [RTMState.ino]
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2026-05-11 Telemetry Fix + Compass Cal: VESC timer decoupled, BIND button repurposed
    VESC telemetry fixes (Findings 1-4 from VESC_Telemetry_Fix.md):
    - Remove dead Serial1.flush() from getVescLoop() (TX drain, not RX)
    - Add foil_power = 0xFF to VESC timeout block (was left stale after drop)
    - VESC moved to own 500ms timer in loop(); no longer coupled to 1s gate
    - vesc_timeout_s default 12s -> 6s in defaultConf
    Compass calibration (compass_cal-2.md):
    - Runtime BIND short-press (falling edge, 50ms debounce) triggers 45s cal
    - blinkBind: 5=starting, 2=success, 10=compass not detected
    - Boot-time pairing/factory-reset guarded by static first_call flag
    - checkButtons() added to loop() to enable runtime butt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
    [BREmote_V2_Rx.h, System.ino, V2_Integration_Rx.ino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]
2026-05-11 Fix version prefix: V3 -> V2.5-Evo on 2026-05-11 header comments
    New firmware lines added this session incorrectly used V3 prefix.
    This is V2.5-Evo (new firmware on existing V2 hardware, not new hardware).
    [System.ino, V2_Integration_Rx.ino, VESC.ino]
2026-05-11 audit: rename all V3 version-header tags to V2.5-Evo across 26 firmware files
    197 replacements: every '// V3 - YYYY-MM-DD' header comment renamed to
    '// V2.5-Evo - YYYY-MM-DD' to match the correct firmware designation.
    V2.5-Evo = new firmware on existing V2 hardware, not a hardware revision.
    Affects RX: BREmote_V2_Rx.h, Compass, ConfigService, GPS, Logger, PWM,
    RTMState, Radio, System, V2_Integration_Rx, VESC, WebUiEmbedded.
    Affects TX: BREmote_V2_Tx.h, ConfigService, Display, GPS, Hall, Init,
    RTMState, Radio, System, Throttle, V2_Integration_Tx, WebUiEmbedded.
    Affects Common: SPIFFSEngine.h, WebConfigEngine.h.
    [BREmote_V2_Rx.h, BREmote_V2_Tx.h, Compass.ino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]
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
